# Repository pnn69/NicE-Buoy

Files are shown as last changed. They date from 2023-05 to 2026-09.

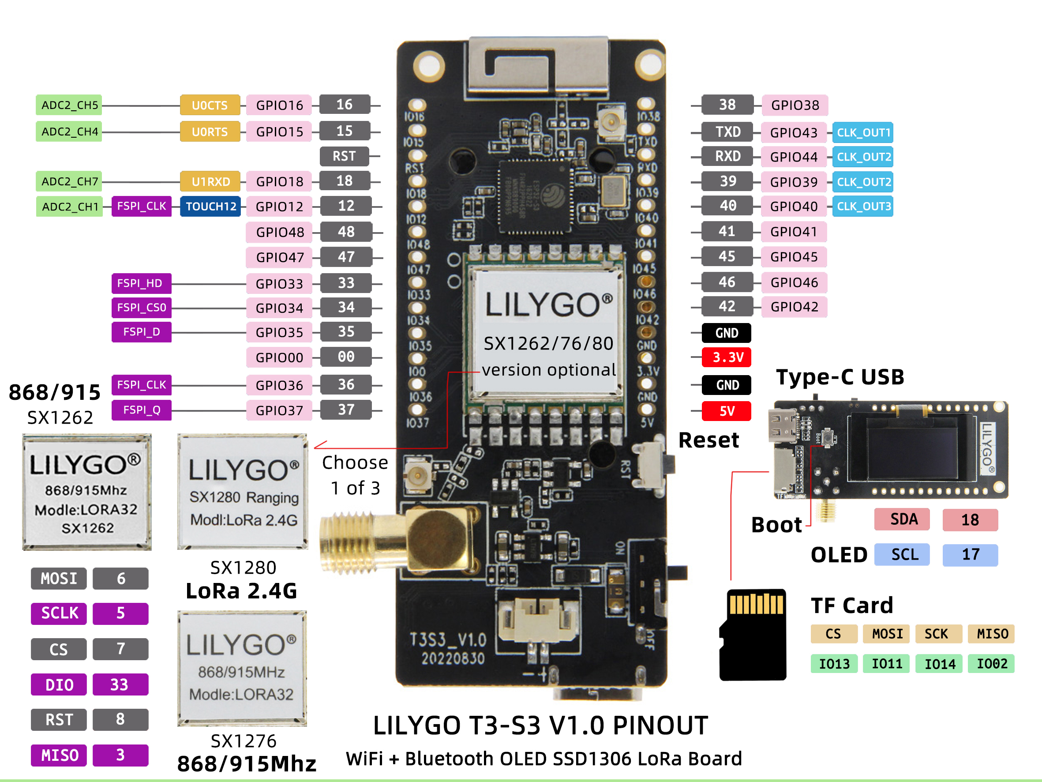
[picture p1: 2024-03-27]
Doc/LilygoEsp32LoraPinout.jpeg

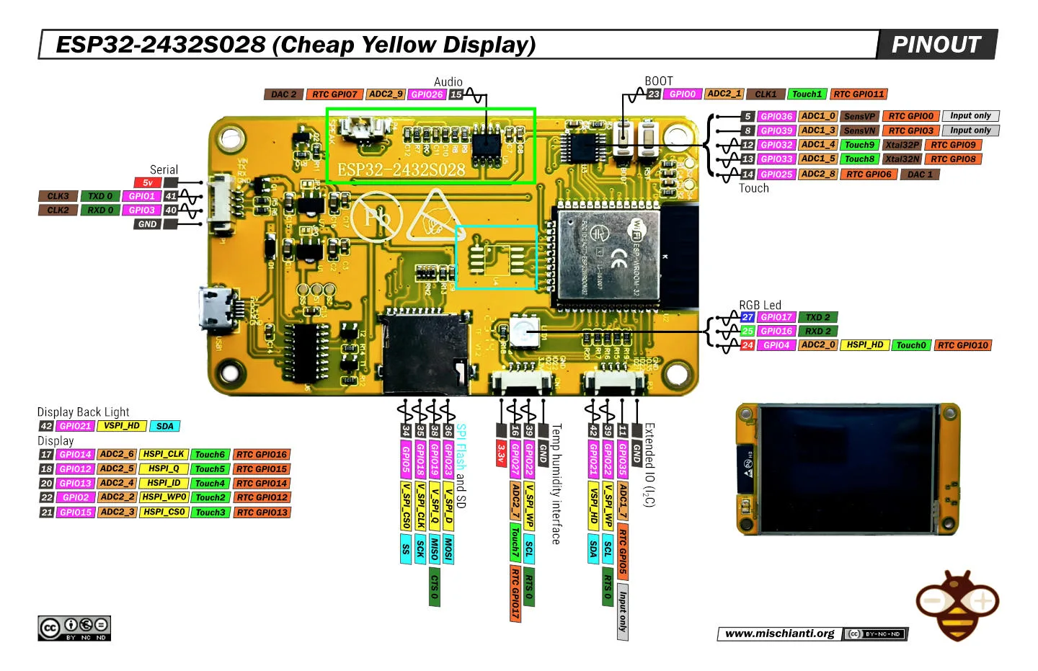
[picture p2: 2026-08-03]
Firmware/RoboCYD/Doc/ESP32-2432S028-ili9341-touch-Cheap-Yellow-Display-pinout-low.jpg.webp

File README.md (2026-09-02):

# NicE-Buoy Autonomous Marine System Firmware

Welcome to the master repository for the **NicE-Buoy Autonomous Marine System**. This codebase powers a highly reliable, dual-processor autonomous marine buoy designed for GPS lock-to-position, remote configuration, automated sailing, and live telemetry tracking over LoRa and WiFi (UDP).

---

## 📌 Project Overview

NicE-Buoy is an industrial-grade marine robotic system consisting of multiple hardware and software components. Each buoy uses a **dual-ESP32 architecture** split into a **Top Unit (RoboTop)** and a **Sub Unit (RoboSub)**, connected by a single-wire half-duplex serial link. This physical decoupling isolates high-frequency navigation, radio communication, and web server tasks (Top) from raw thruster driving, compass polling, and the PID motor loops (Sub).

Alongside the buoys sit two shore-side controllers: **RoboCYD**, a touchscreen unit that doubles as the field WiFi access point, and **RoboLora**, a USB/WiFi LoRa gateway.

---

## 🏗️ System Architecture

```
        ┌───────────────────────────┐        ┌───────────────────────────────┐
        │  RoboPythonDisplay (PC)   │        │  RoboCYD (touchscreen)        │
        │  Tkinter dashboard        │        │  - IS the field AP Robo_WiFi  │
        └────────────┬──────────────┘        │  - LoRa RX task + web UI      │
                     │ UDP / LoRa            └───────────────┬───────────────┘
                     │                                       │
        ┌────────────▼──────────────┐                        │
        │  RoboLora (gateway)       │   UDP 1001 (protocol)  │
        │  USB + WiFi <-> LoRa      │   UDP 1002 (debug log) │
        └────────────┬──────────────┘                        │
                     └───────────────┬───────────────────────┘
                                     │  LoRa 868 MHz  +  WiFi/UDP
┌────────────────────────────────────▼────────────────────────────────────────┐
│                                  RoboTop                                    │
│  - GPS polling (TinyGPS++, 0,0 placeholder rejected)                        │
│  - LoraTask: RF telemetry, ACK retry table (10 slots)                       │
│  - WiFiTask: web dashboard, UDP broadcast, OTA, captive portal, mDNS        │
│  - SercomTask: bridge to the Sub          - Button, buzzer, RGB LEDs        │
└────────────────────────────────────┬────────────────────────────────────────┘
                                     │  single-wire half-duplex UART
                                     │  Top TX 22 / RX 21  <->  Sub RX 5 / TX 18
┌────────────────────────────────────▼────────────────────────────────────────┐
│                                  RoboSub                                    │
│  - Dual ESC thrusters (BB & SB)     - ICM-20948 9-DoF compass + fusion      │
│  - Rudder & speed PID loops         - Owns ALL tuning in NVS                │
│  - Its own web dashboard (24 endpoints) and OTA                            │
└─────────────────────────────────────────────────────────────────────────────┘
```

The codebase is structured into the following decoupled sub-projects:

1.  **`RoboTop` (Top Unit)** — ESP32, FreeRTOS. Acquires GPS, hosts the HTML5 control dashboard, broadcasts telemetry over UDP and LoRa, and delegates motor execution to the Sub.
    Tasks: `GpsTask`, `LoraTask`, `WiFiTask`, `SerialTask` (SercomTask), `buttonTask`, `LedTask`, `buzzTask`.
2.  **`RoboSub` (Sub Unit)** — ESP32, FreeRTOS. Drives the thrusters, reads the compass, runs the PID loops, and is the **authoritative owner of all tuning parameters** (see below).
    Tasks: `CompassTask`, `EscTask`, `SerialTask`, `WiFiTask`, `LedTask`, `buzzTask`. The rudder and speed PIDs live in `pidrudspeed.cpp`.
3.  **`RoboCYD` (Touchscreen Controller)** — ESP32 + 320x240 TFT with resistive touch. Displays the fleet, sends commands, and **raises the field access point `Robo_WiFi`** when no home network is present. Has a dedicated LoRa receive task and serves both a dashboard and a standalone fullscreen map.
4.  **`RoboDependency` (`RoboCompute` + `RoboTone` libraries)** — shared code linked by Top and Sub. Navigation maths (`RouteToPoint`), the unified `RoboStruct`, `formatFloat`, and the telemetry encoder/decoder (`rfCode` / `rfDeCode`).
5.  **`RoboLora` (LoRa Gateway)** — USB-and-WiFi to LoRa gateway with its own web UI. Relays operator commands to the buoys; stamps its outgoing frames with sender ID `0x99`.
6.  **`RoboPythonDisplay` (Python GUI Monitor)** — Tkinter desktop dashboard (`RoboControl.py`) for up to 3 buoys: windroses, thruster indicators, battery voltages, PID menus.
7.  **`RoboChargingStation`** — solar monitoring and charging dock firmware.

### Who owns what

Worth stating plainly, because it drives a lot of the design:

*   **The Sub owns the tuning.** PID gains, compass offset, `holdRad`, thruster inversion and swap all live in the Sub's NVS. The Top holds a RAM copy only, fetched via `SETUPDATA` when the serial link comes up, and shown on the dashboards until the Sub reports again.
*   **`compassOffset`, `revBB`, `revSB` and `swap_BB_SB` are hull-specific** — they describe the physical boat, not the electronics. Move a Sub to another hull and these travel with it and will be wrong until re-entered.
*   **The Sub has no LoRa.** Its only path to the outside world is the serial line to its Top.

---

## 🌐 Network Layout

Every node follows the same priority list:

```
NicE_WiFi  ->  Robo_WiFi  ->  its own AP
```

*   **At home** everything joins `NicE_WiFi`.
*   **In the field**, when no `NicE_WiFi` is in reach, the **CYD becomes `Robo_WiFi`** (password `geenanker`, `192.168.1.1/24`, 8 client slots) and the Tops and RoboLora join it.
*   **A node that finds neither** raises its own AP — `TOP_<id>`, `SUB_<id>`, `LORA_<id>`, password `geenanker`, on `192.168.4.1` — and keeps hunting underneath it. Joining that AP opens the dashboard automatically via a captive portal.
*   **The Sub deliberately skips `Robo_WiFi`**, to keep the CYD's client slots for the Tops and a phone. It costs nothing: the Sub never transmits on UDP anyway, and all of its telemetry reaches you folded into the Top's `TOPDATA`.

**mDNS** gives every node a stable name that works in both modes — `top-<id>.local`, `sub-<id>.local`, `robocyd.local`, `lora-<id>.local`. ArduinoOTA registers the responder; nothing else may call `MDNS.begin()`, as a second responder has crashed this hardware before.

**UDP ports:** `1001` carries the protocol; `1002` carries a plain-text debug log (see the RoboTop README).

---

## 📡 Communication Protocol & Frame Format

The system communicates using a lightweight, proprietary, ASCII-based comma-separated protocol designed to optimize RF bandwidth while remaining human-readable.

### Frame Anatomy
```
$TargetID,SenderID,AckType,CommandType,Status,Param1,Param2,...,ParamN*CRC\n
```

*   **`$`**: Starting sentinel character.
*   **`TargetID`**: Address of the recipient. **All IDs are hexadecimal.** A buoy's ID is the low four bytes of its MAC (e.g. `b7a5b578`). `1` (`BUOYIDALL`) is the broadcast address; `0` is treated as a legacy broadcast.
*   **`SenderID`**: Address of the transmitting station. `99` (i.e. `0x99`) is the web UI / RoboLora and `98` is the CYD display. **These two are the only senders whose broadcasts a buoy will act on** — a broadcast command from a peer buoy is ignored, which is what stops one buoy commanding another.
*   **`AckType`**: Packet type classification:
    *   `1 (GET)`: Request parameter values.
    *   `2 (SET)`: Modify parameter values.
    *   `3 (GETACK)`: Request command execution with receipt verification.
    *   `4 (ACK)`: Receipt confirmation.
    *   `6 (INF)`: Telemetry status update, or an *answer* to a question.
*   **`CommandType`**: Integer mapping to system command (e.g., `51` for `TOPDATA`, `19` for `BUOYPOS`, `83` for `SETUPDATA`, `47` for `DIRDIST`, `21` for `LOCKPOS`, `23` for `DOCKPOS`).
*   **`Status`**: Current state machine status of the buoy (`7 IDLE`, `13 LOCKED`, `16 DOCKED`, …).
*   **`Params`**: Dynamic floating-point or integer parameters depending on the command.
*   **`*`**: End-of-payload delimiter.
*   **`CRC`**: 2-character hexadecimal CRC calculated by XOR'ing all characters between `$` and `*`.

> **Broadcasts that expect an ACK are a trap.** An ACK for `IDr = BUOYIDALL` can never match in `removeAckMsg()`, so a `SET` or `GETACK` broadcast sits in the LoRa retry table for all five retransmits and blocks a slot. Broadcast beacons must use `INF`.

---

## 🚀 Advanced Telemetry Optimizations

### 1. Bandwidth Compression
To maximize LoRa airtime efficiency and range, telemetry strings undergo two compression steps in `RoboCompute.cpp`:
*   **Float Trailing Stripping**: `formatFloat()` trims redundant trailing zeros and decimal points (e.g. `12.5000` becomes `12.5`).
*   **Zero Compression**: `RoboCode()` compresses consecutive zero fields to empty strings (e.g. `,0,0,0,0,` becomes `,,,,,`).

### 2. The Top-to-Sub Link, and Why One-Way Failures Matter
The Top and Sub share **one wire**, half duplex, with hardware separating the two directions (opto-isolated; see `Datasheets/`). The firmware configures two GPIOs per board — Top TX 22 / RX 21, Sub RX 5 / TX 18 — but that is **not** two conductors.

*   **The diagnostic consequence:** if the connector or the wire fails, traffic stops in *both* directions. A failure in **one direction only** therefore cannot be the plug — it is in the direction-separation circuitry, which is per board. Swapping a Sub between hulls localises such a fault to a specific board.
*   `SercomTask` implements **echo filtering**, discarding frames whose sender ID is its own, because a transmitter hears itself on a shared wire.
*   **Implicit ACKs**: any valid `INF` response from the Sub signals that it processed the command, clearing the retry queue without extra traffic.
*   **The Sub sleeps.** After reconnection it sits in power-down and only wakes on an incoming command — send one, wait, then it communicates. Do not read a quiet Sub as a fault until it has been nudged.

### 3. Hardware Self-Healing Watchdogs
*   **LoRa transceiver watchdog**: if transmission fails for 500 ms the SPI/state machine is assumed locked and `InitLora()` forces a full re-init.
*   **Compass watchdog**: static I2C readings under thruster power trigger `COMPASS STUCK - REINIT`.
*   **Serial watchdog**: the Top clears `isSerConnected` after 2 s of silence and re-requests `SETUPDATA` when the Sub returns.
*   **Stack headroom is observable.** The Top's `/data` reports `StkLoop`, `StkLora`, `StkWifi`, `StkSer` and heap figures. A LoRa task running on 100 bytes of stack was the cause of a hard-to-find panic; check these after any change that adds work to a task.

---

## 🧭 In-Field Navigation Calibration State Machines

1.  **In-Field Compass Spin Calibration** — self-guided rotation while measuring magnetic min/max to derive hard-iron offsets.
2.  **In-Field Offset Alignment** — sails a straight leg on compass heading, compares the GPS track, and writes the difference to the stored compass offset.
3.  **Guided 8-Point Compass Calibration** — the hull is turned to the compass's own zero and then indexed round a mechanical fixture 45° at a time, one capture per mark. Produces the 8-point correction table, which is held on the Sub and reported through `SETUPDATA`. The table describes the hull's magnetic deviation only; which way the sensor is bolted in is a separate setting (**Set as North**), applied after the table.

    A GPS-based version of this used to exist, sailing eight 100 m legs and inferring the table from the track. It was removed when the mounting offset moved out of the table's input — its residual arithmetic assumed the old ordering.

---

## 🛠️ Developer Guide

### Prerequisites
*   **Firmware**: [VS Code](https://code.visualstudio.com/) + [PlatformIO IDE](https://platformio.org/).
*   **Python Monitor**: Python 3.10+ with `pyserial` and `tkinter`.

### Compilation & Flash Commands
```bash
pio run                      # build
pio run -t upload            # upload (OTA by default for Top and Sub)
pio device monitor           # serial monitor
```

### Over-The-Air (OTA) Updates
`RoboTop` and `RoboSub` default to `upload_protocol = espota`, so a plain upload goes over the network:

```bash
pio run -t upload --upload-port 192.168.1.71        # by address
pio run -t upload --upload-port top-b7a5099c.local  # or by mDNS name
```

`RoboCYD` and `RoboLora` have **no espota configuration** in their `platformio.ini` (their `upload_port` names a COM port that may not exist), so flash those directly:

```bash
python ~/.platformio/packages/framework-arduinoespressif32/tools/espota.py \
       -i <ip> -p 3232 -f .pio/build/<env>/firmware.bin -r
```

A RoboTop change that touches `data/` also needs `pio run -t uploadfs` — the web page lives in SPIFFS.

> Renaming an SSID or changing the WiFi policy must be rolled out to **the whole fleet at home on `NicE_WiFi`**. A device left on the old scheme cannot be reached in the field.

### Running the Python GUI Dashboard
```bash
pip install pyserial
python RoboPythonDisplay/RoboControl.py
```

---

## 📜 License & Contributions
This project is proprietary and confidential. For contributions, pull requests, or feature requests, contact **Peter de Nijs** (`pnn69pnn@gmail.com`).

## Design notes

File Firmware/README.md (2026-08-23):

# NicE-Buoy Firmware

This directory holds every firmware image in the system. For the system-level picture — architecture, the frame format, the protocol rules and the calibration state machines — see the [repository README](../README.md). This file is the firmware index: what each project is, how they are built and flashed, and the conventions they share.

> These two files used to be near-identical copies, which is how they drifted apart. Keep system-wide material in the root README and firmware-specific material here.

---

## Projects

| Directory | Target | Role | README |
|---|---|---|---|
| `RoboTop` | ESP32 (`esp32dev`) | Buoy top: GPS, LoRa, WiFi, web dashboard, commands the Sub | [link](RoboTop/README.md) |
| `RoboSub` | ESP32 (`esp32dev`) | Buoy sub: thrusters, ICM-20948 compass, PID, owns all tuning | [link](RoboSub/README.md) |
| `RoboCYD` | ESP32 + 320x240 TFT | Touchscreen controller; **is** the field AP `Robo_WiFi` | [link](RoboCYD/README.md) |
| `RoboLora` | ESP32 (`pico32`) | USB/WiFi to LoRa gateway with web UI | [link](RoboLora/README.md) |
| `RoboDependency` | library | `RoboCompute` (maths, `RoboStruct`, codec) and `RoboTone` | [link](RoboDependency/README.md) |
| `RoboChargingStation` | ESP32 | Solar monitoring and charging dock | [link](RoboChargingStation/README.md) |
| `RoboPythonDisplay` | Python | Tkinter desktop dashboard | [link](RoboPythonDisplay/README.md) |

`RoboTop` and `RoboSub` both link `RoboDependency`; change `RoboCompute` and **both** must be rebuilt and reflashed.

---

## 📶 WiFi policy (all devices)

One priority list, identical everywhere:

```
NicE_WiFi  ->  Robo_WiFi  ->  own AP
```

| Device | Priority list | In the field |
|---|---|---|
| RoboCYD | `NicE_WiFi` → *becomes* `Robo_WiFi` | the field AP |
| RoboTop | `NicE_WiFi` → `Robo_WiFi` → `TOP_<id>` | joins the CYD |
| RoboSub | `NicE_WiFi` → `SUB_<id>` | always its own AP |
| RoboLora | `NicE_WiFi` → `Robo_WiFi` → `LORA_<id>` | joins the CYD |

*   `NicE_WiFi` password `!Ni1001100110`; `Robo_WiFi` and every fallback AP use **`geenanker`**.
*   `Robo_WiFi` is `192.168.1.1/24` with **8 client slots** (the Arduino default of 4 is exactly three Tops plus a phone). Per-node fallback APs are `192.168.4.1`, each its own gateway.
*   **The Sub skips `Robo_WiFi` on purpose**, to keep the CYD's slots for the Tops and a phone. Nothing is lost — the Sub never transmits on UDP; its telemetry reaches you inside the Top's `TOPDATA`.
*   Nodes **never stop hunting**: the fallback AP runs in `WIFI_AP_STA`, so a buoy on its own AP keeps looking for a real network underneath it. It will not tear its AP down while a client is connected.
*   No scanning. `WiFi.scanNetworks()` blocks for seconds and drags the single radio off the AP channel; the SSIDs are tried in order with a blind `WiFi.begin()` instead.

**Getting in without an IP address** — two mechanisms, because neither covers both modes:

*   **Captive portal** while the node is an AP: wildcard DNS on port 53 means the phone's own connectivity probe lands on the dashboard. Off when the node is a station, where a 404 must stay a 404.
*   **mDNS** in both modes: `top-<id>.local`, `sub-<id>.local`, `robocyd.local`, `lora-<id>.local`.

> Only `ArduinoOTA.begin()` may initialise mDNS. A second `MDNS.begin()` — or an `MDNS.end()` while OTA holds the responder — has crashed this hardware before. Add records with `MDNS.addService()` on top of the responder OTA created.

> Changing an SSID or the policy must be rolled out to the **whole fleet at home on `NicE_WiFi`**. A device left on the old scheme is unreachable in the field.

---

## 🔌 UDP ports

| Port | Traffic |
|---|---|
| `1001` | protocol frames (`$...*CRC`) — telemetry and commands |
| `1002` | plain-text debug log from Tops and Subs, silent at idle |

Listening to the debug channel is the quickest way to see what a buoy is doing:

```bash
python -c "import socket; s=socket.socket(2,2); s.bind(('',1002));
while 1: print(s.recvfrom(2048)[0].decode('utf-8','replace'), end='')"
```

---

## 🛠️ Build and flash

```bash
pio run                      # build
pio run -t upload            # upload
pio device monitor           # serial monitor
```

| Project | Default upload | Notes |
|---|---|---|
| `RoboTop` | OTA (`espota`, `192.168.1.71`) | a `data/` change also needs `pio run -t uploadfs` |
| `RoboSub` | OTA (`espota`, `192.168.1.189`) | sealed hull, never on USB in practice |
| `RoboCYD` | serial (`COM15`) | **no espota config** — see below |
| `RoboLora` | serial (`COM30`) | **no espota config** — see below |

Override the target per invocation:

```bash
pio run -t upload --upload-port 192.168.1.78
pio run -t upload --upload-port top-b7a5b578.local
```

`RoboCYD` and `RoboLora` name COM ports that may not exist on the machine you are using, but both run ArduinoOTA, so flash them directly:

```bash
python ~/.platformio/packages/framework-arduinoespressif32/tools/espota.py \
       -i <ip> -p 3232 -f .pio/build/<env>/firmware.bin -r
```

Environments: `RoboTop` → `robo-esp`, `RoboSub` → `robo-esp-v3`, `RoboCYD` → `cyd`, `RoboLora` → `pico32`.

---

## Conventions worth knowing before editing

*   **The Sub owns the tuning.** PID gains, `compassOffset`, `holdRad`, `revBB`/`revSB`/`swap_BB_SB` live in the Sub's NVS. The Top keeps a RAM copy fetched via `SETUPDATA`. `compassOffset` and the thruster flags are **hull-specific** and do not belong to the board they are stored on.
*   **The Sub has no LoRa.** Its only link to the outside is the serial line to its Top.
*   **A broadcast must never ask for an ACK.** `IDr = BUOYIDALL` with `ack = SET`/`GETACK` can never be matched in `removeAckMsg()` and jams a LoRa retry slot for five retransmits. Use `INF` for beacons.
*   **Only `0x99` (web/RoboLora) and `0x98` (CYD) may command by broadcast.** A buoy ignores broadcast commands from a peer buoy — that is what stops one buoy driving another.
*   **Watch task stack headroom.** The Top's `/data` exposes `StkLoop`, `StkLora`, `StkWifi`, `StkSer`, `HeapFree`, `HeapMin`, `HeapMaxBlk`. A LoRa task left with 100 bytes of stack caused a panic that looked like everything except what it was.

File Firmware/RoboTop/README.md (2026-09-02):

# RoboTop — Autonomous Marine Buoy Master Supervisor Firmware

The **`RoboTop`** firmware runs on the master ESP32 microcontroller of the NicE-Buoy Autonomous Marine System. It serves as the primary intelligence, networking, and supervisory node, managing global positioning, wireless telemetry channels, client-facing control dashboards, and delegating physical motor actions to the Sub Unit (`RoboSub`).

---

## 🏗️ Architecture & Core Tasks

RoboTop leverages FreeRTOS to coordinate real-time operations across the ESP32's dual cores:

```
┌─────────────────────────────────────┬─────────────────────────────────────┐
│               Core 0                │               Core 1                │
├─────────────────────────────────────┼─────────────────────────────────────┤
│ WiFiTask   8192  web, UDP, OTA      │ LoraTask   8192  SPI long-range RF  │
│ SerialTask 6000  link to the Sub    │ GpsTask    2000  TinyGPS++ polling  │
│                                     │ buttonTask 2048  press detection    │
│                                     │ LedTask    2000  / buzzTask 2048    │
└─────────────────────────────────────┴─────────────────────────────────────┘
                 loop() on core 1: navigation, state machine, RF dispatch
```

The numbers are stack sizes in bytes, and they matter. `LoraTask` was once given 4000 and ran with **100 bytes of headroom**, which tripped the stack canary under load and produced a panic that pointed at every task except the guilty one. Live headroom is published in `/data` as `StkLoop`, `StkLora`, `StkWifi`, `StkSer` — check it after any change that adds work to a task.

---

## ⚡ Core Functional Modules

### 1. GPS Acquisition & Navigation Telemetry
*   **Hardware Interface**: GPS module over UART, polling raw NMEA sentences.
*   **Sentence Parsing**: `TinyGPSPlus` extracts latitude, longitude, heading and speed over ground.
*   **Fix validity**: a fix requires `isValid()` **and** an age under 2000 ms **and** a position that is not `0,0`. `isValid()` alone only means "a position field was parsed" — it stays true across a sentence carrying zeros, and passing that on sends the rest of the firmware chasing a point off the coast of Africa.

### 2. Long-Range LoRa Telemetry (`loratop.cpp`)
*   **Hardware Interface**: SPI LoRa transceiver for bidirectional telemetry with the shore station and the other buoys. **433 MHz** (`LoRa_frequency` in `loratop.h`), library defaults otherwise — SF7, 125 kHz, CR 4/5, hardware CRC on. The band is `#define`d separately here, in RoboLora and in RoboCYD, and all three must match; see the RoboLora README.
*   **Retry & ACK Protocol**: `pendingMsg[10]` holds frames sent with `ack = GETACK` or `SET`, retransmitting each up to 5 times until acknowledged.
    > **A broadcast must never ask for an ACK.** An ACK for `IDr = BUOYIDALL` can never match in `removeAckMsg()`, so the frame occupies its slot for all five retransmits and re-broadcasts each time. Beacons use `INF`.
*   **Self-Healing SPI Watchdog**: if transmission fails over a 500 ms window the radio is assumed locked and `InitLora()` forces a full re-init.

### 2b. The transparent repeater

A node relays frames addressed to **someone else**, in case that someone is out of the sender's
range but inside ours. Every rule below exists because the naive version of it failed in the field,
so they are worth reading before changing any of them. Same design in `RoboLora`.

**Unicast only — with one exception.** Broadcasts are not relayed. They used to be, simply because
a broadcast is not "addressed specifically to us" and so fell through into the relay branch. All
periodic telemetry is broadcast (`handleTimerRoutines` sets `IDr = BUOYIDALL`), so every Top
rebroadcast every other Top's telemetry. At SF7/125 kHz a 116-byte `TOPDATA` is ~195 ms of airtime,
so three locked buoys sending one frame a second came to roughly **195% channel occupancy**. The
channel could not carry it, and what got dropped was the traffic that mattered — a COMPUTE STARTLINE
would compute and its `SETLOCKPOS` frames would never arrive. Relaying a broadcast buys nothing
anyway: a node close enough to hear the relay had almost certainly heard the original, and every
buoy broadcasts its own telemetry regardless.

The exception is **`LORA_LINK`**, and it is an exception precisely because neither of those
arguments holds: the whole point of a link report is to arrive from a node you *cannot* hear
directly, and nobody else can produce it on that node's behalf. One frame a minute per node is about
0.2% of the channel.

**Dedup cache** (`checkAndRecordRepeaterMessage`, 16 entries, 20 s). A frame is matched verbatim and
relayed at most once per 20 s window. This is what stops a relay going round in circles between two
nodes that can both hear each other.

**Deferred, staggered relays.** A relay is queued with a due time, not transmitted from inside
`onReceive()`. Synchronous relaying meant every node that heard the frame relayed it in the same
millisecond, so the relays collided with each other — and a node is deaf while it transmits, so each
one also missed whatever else was on the air. Nothing about that design could work with more than
one relay in the field.

The delay comes from the node's **own MAC** (`repeatDelayMs()`), folded down to one of
`REPEAT_NODE_SLOTS`, so two nodes holding the same frame are never due at the same moment. Pure
randomness would still collide occasionally; a MAC-derived slot cannot, provided the two boards fold
to different slots. A small random jitter is added only to break the tie when they do not.

| Constant | Value | Why |
|---|---|---|
| `REPEAT_SLOTS` | 4 | relays that may be waiting at once |
| `REPEAT_NODE_SLOTS` | 5 | distinct per-MAC time slots |
| `REPEAT_SLOT_MS` | 250 | wider than the airtime of any frame relayed, so slot 0 finishes before slot 1 starts |
| `REPEAT_BASE_MS` | 40 | dead time before slot 0, lets the sender's tail clear |
| `REPEAT_JITTER_MS` | 60 | tie-break when two MACs fold to the same slot |
| `REPEAT_EXPIRY_MS` | 3000 | give up on a relay the radio will not accept |

**The slot budget is bounded by the retry interval, not chosen freely**: `4 x 250 + 40 + 60 =
1100 ms`, comfortably inside the ~1500 ms the sender's retry table waits. Widen the slots or add
more and relays start landing after the retransmit they were meant to save.

**Cancel on heard** (`cancelRepeat`). Before anything else in `onReceive()`, a queued relay matching
the frame just heard is dropped — somebody beat us to it, or the sender resent it. Deliberately
ahead of the early returns, so it applies to frames addressed to us as well. Combined with the
stagger, this means **in practice only the lowest-slot node in range actually transmits**: the
others hear that relay, drop their copy, and the frame reaches the far node exactly once.
`cancelRepeatOnAck` does the same when an ACK proves the target already has it — matched on
`cmd` + `target_id` rather than on the text, because the ACK is not the frame.

**Two boards can share a slot**, and with three Tops and five slots that is not unlikely. Not fatal:
both relay at once, that relay is lost to the collision, and the sender's next retransmit produces a
fresh attempt with newly drawn jitter. The stagger removes the *guaranteed* collision the old
synchronous design had; it does not have to remove every possible one.

**A wedged radio does not disable the repeater.** If `sendLora()`'s inter-packet guard keeps
refusing, the slot stays busy and is retried next pass rather than being dropped — the old
fire-and-forget call lost the relay on every guarded return. After `REPEAT_EXPIRY_MS` the relay is
stale enough to be useless and the slot is freed, which is also what stops one stuck transceiver
silently holding every slot.

### 2c. The button

**Every action ends in a long press.** Nothing is bound to a short-press-only sequence, and that is
the design rather than an accident of it. This button is on a buoy that gets knocked, carried and
stowed, and the previous map had *lock/unlock on a single short press* and *sail to the dock on
five*. Both were one accidental knock away from a boat leaving on its own. A long press cannot be
produced by a bump, so the short presses became a selector and the long press became the trigger.

`countKeyPressesWithTimeoutAndFinalLongPress()` returns `100 + (presses in the sequence)`, and the
closing long press is one of them — so "three short then long" arrives as `104`.

| Sequence | Code | Action | On success | On failure |
|---|---|---|---|---|
| long | `101` | lock / unlock | rising arpeggio (lock) or descending (unlock) | error tone — no GPS fix |
| short, long | `102` | align start line (`COMPUTESTART`) | rising | error tone |
| short ×2, long | `103` | align track (`COMPUTETRACK`) | rising | error tone |
| short ×3, long | `104` | extend the start line by `START_LINE_STEP_M` (`EXTENDSTART`) | rising | error tone |
| short ×4, long | `105` | sail to the dock position (`DOCKING`) | rising | — |
| short ×9, long | `110` | store here as the dock position (`STOREASDOC`) | rising | error tone |

Anything else beeps the error tone and does nothing — deliberately including every plain short
press. Silence would be indistinguishable from a flat battery or a jammed switch.

> **`110` stores wherever the buoy IS.** Nine short presses and a long one is an easy sequence to
> arrive at by accident, it overwrites the stored dock with the buoy's current position, and nothing
> keeps the previous value. That happened on the bench, 3.8 km from the water, and there was no way
> to put it back - so `SETDOCKPOS` (22) now writes the dock from coordinates over the air. The
> command number and the codec always existed; only the Top's handler was missing. `DOCKPOS` (23)
> with `ack = GET` reads it back out of NVS, which is how a write should be checked.

> **Two codes have MOVED.** `105` used to be store-as-dock and is now *dock*; `110` used to be the
> desk magnetic calibration and is now *store-as-dock*. Muscle memory from the old scheme will do
> the wrong thing.

**Extend is not a re-align.** `EXTENDSTART` keeps the line's midpoint *and its bearing* and only
moves the ends apart, half the step each. It is the answer to "same line, a bit longer", which is
not what `COMPUTESTART` does — that squares the line to the wind, and a race officer asking for ten
more metres is not asking to have the line rotated as well. Consequently it needs **no wind reading
at all**, so unlike the two align actions it still works on a buoy whose compass has failed. It
takes the same two-locked-buoys guard, because an unlocked buoy carries a stale target and the line
would be extended through wherever it last was. Roles are left untouched: pushing a buoy further out
along the bearing it is already on cannot change which side of the line it is.

The step is fixed at 10 m (`START_LINE_STEP_M`) rather than settable. This is the button on the
buoy: it has no way to show a number and no way to take one back. Press it twice for twenty metres.

#### Two beeps that were missing

*   **Storing the dock position** played `beep(1000)` — a single flat 1000 Hz tone, which is
    *exactly* the tone the button plays on every physical press. "The dock position is stored" was
    indistinguishable from "I felt you press the button". It plays the rising arpeggio now, like
    every other successful action.
*   **Locking without a GPS fix** was completely silent — the long press did nothing and said
    nothing, which reads the same as a flat battery, a jammed switch or a missed press. It is also
    the moment the operator most needs telling, because the boat is already in the water. It beeps
    the error tone now.

Everything else already gave the right feedback: `LOCKING` the rising arpeggio, `IDLING` the
descending unlock pattern, and every compute a rising tone on success and the error tone on refusal.

### 3. WiFi, Web Dashboard and OTA (`topwifi.cpp`)
*   **Priority list**: `NicE_WiFi` → `Robo_WiFi` → its own `TOP_<id>` AP. No scanning — the SSIDs are tried in order with a blind `WiFi.begin()`, because `WiFi.scanNetworks()` blocks for seconds and drags the single radio off the AP channel.
*   **Passwords**: `NicE_WiFi` is `!Ni1001100110`; `Robo_WiFi` and the fallback AP are **`geenanker`**.
*   **The fallback AP keeps hunting.** It runs in `WIFI_AP_STA` on `192.168.4.1` (its own gateway, 8 client slots) and continues looking for a real network underneath — but it will **not** tear itself down while a client is connected.
*   **Captive portal** while in AP mode: wildcard DNS on port 53, so joining `TOP_<id>` opens the dashboard by itself. Disabled as a station, where a 404 must remain a 404.
*   **mDNS**: reachable as `top-<id>.local` in both modes. Only `ArduinoOTA.begin()` may initialise the responder — a second `MDNS.begin()` has crashed this hardware.
*   **HTML5 Dashboard**: served from SPIFFS and streamed straight from the file, not cached in a RAM `String` (a fragmented heap silently truncated the page mid-`<script>`). The page **polls `/data`**; there is no WebSocket on the Top.
*   **Endpoints**: `/` (dashboard), `/data` (JSON telemetry), `/command` (actions).
*   **Dual-rate transmit scheduler**: UDP telemetry every **250 ms** for fluid web feedback; LoRa throttled to **5 s** with randomised jitter for collision avoidance, battery and duty-cycle reasons.

### 4. Single-Wire Half-Duplex Serial Bridge (`sercom.cpp`)
*   **Physical layer**: **one shared wire**, half duplex, with hardware separating the directions (opto-isolated). The firmware names two GPIOs per board — Top **TX 22 / RX 21**, Sub **RX 5 / TX 18** — but that is not two conductors.
    > **Diagnostic consequence:** a bad connector or wire stops traffic in *both* directions. A failure in **one direction only** is therefore in the direction-separation circuitry, which is per board — swap the Sub between hulls to localise it.
*   **Echo filtering**: a transmitter hears itself on a shared wire, so frames whose sender ID is our own are discarded.
*   **Implicit ACKs**: any valid `INF` from the Sub clears the retry buffer.
*   **Watchdog**: `isSerConnected` clears after 2 s of silence and a fresh `SETUPDATA` request is issued when the Sub returns.
*   **The Sub sleeps** after reconnection and only wakes on an incoming command — send one, wait, then it talks.

### 5. Who owns the tuning
The **Sub** owns it. PID gains, `compassOffset`, `holdRad`, `revBB`/`revSB`/`swap_BB_SB` live in the Sub's NVS; the Top keeps a RAM copy fetched with `SETUPDATA` when the serial link comes up. `/data` reports `rev` (the count of replies received) and `SubOk` (serial alive) — `rev: 0` with real values elsewhere means the Top has never heard back and is running on zeroed gains.

**The mirror is re-read every `SUB_SETUP_RESYNC_MS` (20 s), not only on connect.** Anything that
changes a setting without going through a Setup dialog — `SET_AS_NORTH`, the Sub's own web page,
an in-field calibration — used to leave this Top serving a stale value indefinitely; measured on the
bench, a Sub on `-43.30` against a Top still reporting `-53.00` minutes later. Re-asking the owner
is the only thing that covers all of them, and it is self-healing.

> **Consequence for anything that reads `/data` or the broadcast live.** The reply goes out to
> `BUOYIDALL` on **both** transports, asked for or not. That is safe for the web Setup dialog, which
> fills its fields once on open, and it was written with that in mind. It is *not* safe for a client
> that edits a live-updating copy of the same struct: the CYD's Setup screen did exactly that, and
> every value dialled in was replaced by the buoy's own a few seconds later. The fix belongs at the
> reading end — see the RoboCYD README — but the behaviour to design against is here.

### 6. Automated Regatta Start Line & Track Calculations
To facilitate competitive sailing regattas, RoboTop coordinates the positions of multiple buoys to automatically establish a fair, geometrically synchronized starting line:

*   **Intelligent Triangulation & Role Determination (`calcTrackPos`)**: Rather than relying on static or arrival-order database slots, RoboTop uses geometric triangulation and wind vectors to determine the roles of the three buoys (`PORT`, `STARBOARD`, `HEAD`):
    *   **Starting Line Identification**: Computes the Great-Circle distances between all three buoy pairs. The two buoys with the **shortest distance** between them are the starting line pins; the furthest is the upwind **HEAD** buoy.
    *   **Port vs. Starboard Allocation**: Calculates the bearing between the two pins and measures the signed smallest angular difference against $W_{\text{dir}}$. Positive ($\ge 0^\circ$) makes the first buoy **PORT**; negative makes it **STARBOARD**.
*   **$W_{\text{dir}}$ is the mean of BOTH pins' wind, not one buoy's (`meanWindDir`)**: it used to
    be `rsl[0].wDir` — whichever buoy the command happened to reach. Two anemometers a line's length
    apart disagree by a few degrees in steady air and by rather more in a shifty one, and there is
    no reason to prefer either; the mean squares the line to the wind *across* the line, which is
    the wind the fleet actually starts in. In a three-buoy course the upwind **HEAD** mark is left
    out of the average on purpose — it is no part of the line, and it is the furthest from where the
    start happens. All three consumers now use it: `recalcStartLine()`, `reCalcTrack()` (which hangs
    the head mark's bearing, the offset back down to the line and the starboard side off this one
    figure) and `calcTrackPos()`. Slot 0 remains the fallback, because `handleStatus()` puts this
    buoy's filtered wind there and the compute guards have already refused to run without it.
*   **Geographical Midpoint & Width**: Computes the pins' midpoint by coordinate average and the line width $d$ by Haversine.
*   **Wind-Aligned Perpendicular Squaring (`recalcStartLine`)**: The line must be exactly perpendicular to the wind:
    *   Port end bearing: $\theta_{\text{Port}} = (W_{\text{dir}} + 270^\circ) \bmod 360^\circ$
    *   Starboard end bearing: $\theta_{\text{Starboard}} = (W_{\text{dir}} + 90^\circ) \bmod 360^\circ$
*   **Vector Position Projection (`adjustPositionDirDist`)**: Projects new targets outward from the midpoint along those bearings by $d/2$, squaring the line to the wind while keeping midpoint and length intact. *Length intact* now holds exactly: this function placed with an earth radius of 6371000 m while `distanceBetween()` measured with 6372795 m, so measuring $d$ and then placing at $d$ returned $1.000282\,d$ and every press of ALIGN STARTLINE grew the line by 0.028%. Both use `EARTH_MEAN_RADIUS`. It was 9 mm on a 31 m line and never the reason a line looked a different length — but the whole design of `recalcStartLine()` is that measuring and placing are inverses, and they were not.
*   **The line is computed from the lock TARGETS, not the hulls.** The screens draw it between the
    actual positions, because that is what the crew can see; the arithmetic deliberately does not.
    Feed it hull positions and each press picks up wherever the buoys were wandering inside their
    hold radius, so the line changes length every time it is aligned. Targets are fixed, so the
    length is preserved. You see the hulls, the maths uses the targets.
*   **Asynchronous Coordination Broadcast (`SENDTRACK`)**: Dispatches updated coordinates to Port, Starboard and Head over LoRa.

### 7. Advanced Circular Wind Telemetry & Standard Deviation
*   **Circular Vector Addition (`averageWindVector`)**: Arithmetic averaging fails at the $360^\circ$ wrap (the mean of $350^\circ$ and $10^\circ$ is $180^\circ$ arithmetically but $0^\circ$ physically). Each sample $A_i$ is decomposed into unit vectors:
    $$x_i = \cos(A_i \times \tfrac{\pi}{180}), \quad y_i = \sin(A_i \times \tfrac{\pi}{180})$$
    and recombined with the four-quadrant arctangent:
    $$W_{\text{dir}} = \text{atan2}(\bar{y}, \bar{x}) \times \tfrac{180}{\pi}$$
*   **Yamartino Circular Standard Deviation (`deviationWindRose`)**: from the mean resultant length $R$
    $$R = \frac{\sqrt{(\sum \cos A_i)^2 + (\sum \sin A_i)^2}}{N}, \qquad W_{\text{std}} = \sqrt{-2 \ln R} \times \tfrac{180}{\pi}$$
    $R = 1$ is perfect alignment, $R = 0$ complete dispersal.

### 8. Command Routing Rules (`handleRfData`)
*   `IDr` is matched against our MAC; `1` (`BUOYIDALL`) and `0` are broadcasts.
*   A **broadcast command is only obeyed when the sender is `0x99` (web/RoboLora) or `0x98` (CYD)**. A broadcast from a peer buoy is ignored — this is what stops one buoy commanding another.
*   Frames that are not for us are **bridged to the other interface** (UDP↔LoRa), never back out the one they arrived on, which would loop.
*   `DOCKPOS` is a *question*. The answer is addressed to the asker and sent as `INF`, and an `INF` frame is never answered — otherwise two Tops answer each other's answers indefinitely.

---

## 🩺 Diagnostics

*   **Debug channel** — plain text broadcast on **UDP 1002**, silent at idle. Carries every non-telemetry RF and serial frame, the DOCK/DOCKPOS step markers and every beep with the line that requested it.
*   **Breadcrumbs surviving a panic** — held in `RTC_NOINIT` memory and reported next boot as `Crumb`, `CrumbLora`, `CrumbWifi`, `CrumbSer`. `90–96` = loop phase, `1000+cmd` = RF command dispatched, `2000+cmd` = serial command, `200–206`/`300–303`/`400–403` = LoRa/Sercom/WiFi task.
    > A **power cycle wipes RTC RAM** and the evidence with it. A reset-pin press or a panic reboot preserves it.
*   **`/data` health fields** — `Uptime`, `ResetReason`, `SubOk`, `rev`, the four `Stk*` figures and `HeapFree` / `HeapMin` / `HeapMaxBlk`.

---

## 🛠️ Building & Flashing

PlatformIO environment **`robo-esp`** (`board = esp32dev`). Dependencies: `RoboCompute`, `RoboTone`, Arduino-PID-Library, TinyGPSPlus, FastLED, arduino-LoRa, ArduinoOTA.

```bash
pio run                                              # build
pio run -t upload                                    # OTA, default 192.168.1.71
pio run -t upload --upload-port top-b7a5b578.local   # a different unit
pio run -t uploadfs                                  # required after any data/ change
```

`upload_protocol = espota`, so a plain upload goes over the network — the Tops are not normally on USB.

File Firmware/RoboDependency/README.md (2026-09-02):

# RoboDependency — Shared Static Libraries & Algorithmic Engines

The **`RoboDependency`** workspace houses core statically-linked C++ library engines shared across both the **`RoboTop`** (Master Supervisor) and **`RoboSub`** (Locomotion Engine) firmwares. Decoupling these common engines ensures mathematical consistency and guarantees zero duplication in message encoding.

---

## 🏗️ Library Structure

```
                             ┌────────────────────────┐
                             │     RoboDependency     │
                             └───────────┬────────────┘
                  ┌──────────────────────┴──────────────────────┐
                  ▼                                             ▼
       ┌────────────────────┐                        ┌────────────────────┐
       │    RoboCompute     │                        │      RoboTone      │
       │ - Navigation math  │                        │ - beep() sounder   │
       │ - RoboStruct       │                        │ - Tone / melody    │
       │ - Codec + CRC      │                        │   tables           │
       │ - Zero-compression │                        │                    │
       └────────────────────┘                        └────────────────────┘
```

---

## ⚡ Module Breakdown

### 1. `RoboCompute` Library
`RoboCompute` forms the computational backbone of the buoy system, implementing localized navigation math and data compression pipelines:

*   **Great-Circle Path Math (`RouteToPoint()`)**:
    *   Calculates shortest path bearing angles (0 to 360 degrees) and distances (in meters) between arbitrary GPS coordinates (latitude/longitude) on the earth's surface.
    *   Supplies the core error vectors utilized by the high-speed rudder and speed PID tasks on the Sub Unit.
*   **Unified State Struct (`RoboStruct`)**:
    *   Establishes the global data structure (`mainData`) representing the absolute physical state of the buoy (GPS status, heading, thruster duty cycles, battery state, target waypoints, and PID tuning variables).
    *   Allows seamless, thread-safe data serialization across task loops via mutex locks.
*   **Bandwidth-Saving Float Trailing Stripping (`formatFloat()`)**:
    *   Trims redundant trailing zeros and decimal points (e.g., `24.0000` is packed to `24`, and `1.230` to `1.23`) before packaging payload variables, significantly reducing string lengths.
*   **Zero-Compression Payload Packing (`rfCode()` / `rfDeCode()`)**:
    *   Scans finalized ASCII CSV payloads for repetitive zeros representing inactive fields (e.g., zero error, zero speeds, empty target parameters) and replaces them with adjacent commas (e.g., `,0,0,0,0,` is packed to `,,,,,`).
    *   This dual optimization reduces the average LoRa payload size by up to **45%**, decreasing airtime, saving battery, and reducing channel congestion.

*   **Frame CRC (`addCRCToString()` / `verifyCRC()`)** — also in `RoboCompute`, not `RoboTone`:
    *   Computes a longitudinal parity byte (XOR) over every character between the sentinel `$` and
        the delimiter `*`, rendered as a 2-character hexadecimal string.
    *   Incoming frames whose computed checksum does not match the trailing CRC are discarded.
*   **Circular wind statistics (`averageWindVector()`, `deviationWindRose()`)** — vector averaging
    and Yamartino circular standard deviation, so a wind direction either side of North averages
    correctly instead of landing on 180°.
*   **`meanWindDir(dirA, stdA, dirB, stdB, fallback)`** — the wind a start line is squared against:
    the mean of what the **two line-end buoys** report. It used to be one buoy's reading, whichever
    the command happened to reach. Same circular maths and the same reason as above; a buoy
    reporting `0/0` has *no* reading rather than a northerly, so it is left out, and two exactly
    opposite readings are a fault rather than a wind and return the fallback. Used by
    `recalcStartLine()`, `reCalcTrack()` and `calcTrackPos()`.
*   **`extendStartLine(rsl, metres)`** — grows the start line by `metres`, half to each end,
    keeping the midpoint **and the bearing**. Deliberately not `recalcStartLine()` with a different
    length: that one squares to the wind, and rotating the line is not part of "make it longer". It
    therefore reads no wind at all. Both bearings are taken before either end is written back — move
    one end first and recompute the second bearing from the new midpoint, and the pair can swap ends
    and motor through each other, which is the failure `starboardGoesToFirst()` exists to prevent.
    `trackPos` is left alone, and `MIN_START_LINE_M` stops a line being shrunk to a point, which
    would leave no bearing to grow it back along. New `EXTENDSTART` command, appended at the END of
    `msg_t` so every existing number is unchanged and an un-reflashed node still decodes what it did
    before.
*   **One earth radius (`EARTH_MEAN_RADIUS`)** — `distanceBetween()` measured with 6372795 m while
    `adjustPositionDirDist()` placed with 6371000 m, so placing a point at distance $d$ and
    measuring back returned $1.000282\,d$. `recalcStartLine()` does exactly that round trip, so
    every re-align grew the start line by 0.028%. The two must agree: the whole design of that
    function is that measuring and placing are inverses.

### 2. `RoboTone` Library
`RoboTone` is the **audible feedback** library — it has nothing to do with checksums.

*   **`void beep(int sound, QueueHandle_t buzzer)`** — queues a tone, a melody or an error pattern
    onto a buzzer task. Callers pass a sound id: `1` is the confirmation arpeggio, `2` the
    unlock/idle pattern, `-1` the error tone, and a large value such as `1000` a single fixed tone.
*   **`6` is "that landed in NVS"** — one 2000 Hz chirp for 80 ms, added for settings saves. Its own
    id rather than a reuse, because each neighbour already means something and a save has to be told
    apart from all of them: `10` is the button-press tick, `1` a computation that produced a result,
    `5` the compass-table tune, `-1` failure. Long enough to hear at arm's length over an outboard,
    short enough not to be a tune.

> **Ids carry meaning — check before reusing one.** `beep(-1)` is *failure*, and it had been wired
> to the success path of `SET_AS_NORTH` and, previously, of a compass save in `subwifi.cpp`. A good
> save that sounds like a failure teaches the operator to ignore the buzzer, which costs more than
> the missing feedback did.
*   Holds the tone and melody tables (`hz`, `duration`, `repeat`, `pause`) used by both firmwares.

> Sound is the buoy's only feedback in the field, so beeps carry real diagnostic weight. Note that
> a Top emits a single beep on boot — a burst of beeps usually means it has restarted several
> times, not that it acknowledged several commands.

---

## 🛠️ Integration
Both `RoboTop` and `RoboSub` reference these libraries inside their PlatformIO build
configurations via `lib_extra_dirs`:

```ini
lib_extra_dirs =
    ../RoboDependency

lib_deps =
    RoboCompute
    RoboTone
```

> ## ⚠️ Change this, rebuild both
>
> `RoboCompute` is statically linked into **both** firmwares. A change here is not live until
> `RoboTop` *and* `RoboSub` have both been rebuilt and reflashed — and because `RoboStruct` and the
> codec are shared, a half-updated fleet can end up decoding frames differently at each end. Never
> leave this library uncommitted while the firmwares that depend on it are committed.

`RoboLora` links `RoboCompute` too, so a codec change means rebuilding **three** firmwares.
`RoboCYD` is the exception: it links neither library and parses frames with its own code, so a
protocol change has to be mirrored there by hand.

**The wind mean is one of those hand-mirrored things.** It exists three times on purpose —
`meanWindDir()` here for the squaring the Top performs, `mean_wind_dir()` in the CYD firmware for
the roles and the wind label on the touchscreen, and `mapMeanWindDir()` in `RoboCYD/data/index.js`
for the web map. They must stay in step: if they drift, the three views disagree about which end of
the line is starboard, and there is nothing on any screen to say which one is lying.\n

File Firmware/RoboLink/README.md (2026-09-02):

# RoboLora — Long-Range RF USB Gateway Firmware

The **`RoboLora`** firmware runs on the shore-based or vessel-tethered LoRa-to-USB gateway controller. It serves as the physical hardware transceiver link connecting the PC monitoring station with the autonomous buoys over miles of open water.

---

## 🏗️ Gateway Architecture & Functionality

RoboLora manages the relay of long-range telemetry frames with low latency, bridging long-range RF signals directly into a physical PC COM interface:

```
┌─────────────────┐             ┌───────────────────┐             ┌─────────────────┐
│     RoboSub     │   LoRa RF   │     RoboLora      │ USB Serial  │RoboPythonDisplay│
│       or        │◀───────────▶│   - LoraTask      │◀───────────▶│    (PC GUI)     │
│     RoboTop     │             │   - SercomTask    │             │                 │
└─────────────────┘             └───────────────────┘             └─────────────────┘
```

---

## ⚡ Core Functional Modules

### 1. LoRa Physical Transceiver Layer (`LiLlora.cpp` / `LiLlora.h`)
*   **Hardware Interface**: Controls an SPI-connected LoRa transceiver (e.g., RFM95/SX1278) to broadcast and receive long-range RF packets.
*   **433 MHz, and nothing else is configured.** `LoRa_frequency` is `433E6` (`io.h`). Bandwidth,
    spreading factor, coding rate and TX power are **not** set anywhere, so the radio runs the
    Sandeep Mistry library defaults: **SF7, 125 kHz, CR 4/5, 17 dBm, sync word `0x12`**. This entry
    used to claim full runtime configuration of all of those, which was never true of any node — a
    reader sizing an airtime budget or chasing a range problem would have gone looking for tuning
    that does not exist. SF7/125 kHz is where the ~195 ms of channel occupancy per `TOPDATA` frame
    comes from, which is why the Top throttles telemetry while station keeping.
*   **The band is a compile-time `#define`, repeated in three files that must agree**:
    `RoboLora/src/io.h`, `RoboTop/src/loratop.h` (both `LoRa_frequency`) and
    `RoboCYD/src/cyd_lora.cpp` (`LORA_BAND`). There is no shared header and no runtime setting, so
    changing band means editing three places and reflashing everything; miss one and that node goes
    silent without an error — it will transmit and receive perfectly happily, just nowhere anyone
    is listening. The CYD prints `LoRa: 433M` on its boot screen, which is the quickest confirmation
    of what a handheld is actually running.
*   **Hardware CRC is enabled on all three** (`LoRa.enableCrc()`). It has to be enabled or disabled
    fleet-wide: a receiver expecting a CRC will drop every frame from a transmitter that does not
    append one.
*   **Asynchronous Polling**: Runs an optimized FreeRTOS background task to monitor the LoRa FIFO buffer, raising real-time interrupts upon packet arrivals to prevent buffer overflows.

### 1b. The gateway is a first-class node on the air

RoboLora does not only relay. It **reports its own link quality** (`LORA_LINK`, cmd 94, once a
minute) and it **repeats** for others, so it transmits under its own ID like any buoy. Worth knowing
because it is by some margin the strongest transmitter on the network — measured at the two Tops it
arrives at -76 and -83 dBm against a handheld's -102 and -103 — which is exactly why standing it
near a weak node is useful, and exactly why the repeater was added.

#### The repeater

RoboLora had **no** repeater until recently, so standing the gateway near a weak node did nothing
for anybody but the gateway. It has one now, ported from RoboTop with the same constants
(`REPEATER_CACHE_SIZE` 16 / `REPEATER_TIMEOUT_MS` 20 s, `REPEAT_SLOTS` 4, `REPEAT_NODE_SLOTS` 5,
`REPEAT_SLOT_MS` 250, `REPEAT_BASE_MS` 40, `REPEAT_JITTER_MS` 60, `REPEAT_EXPIRY_MS` 3000) — they
must stay equal across firmwares, because the slot budget is sized against the *sender's* retry
interval and the sender may be any node.

**The full explanation of the mechanism, and of why each rule exists, is in the RoboTop README
(§2b).** In short: a frame addressed to somebody else is relayed in case that somebody is out of the
sender's range but in ours; unicast only, because relaying broadcast telemetry once measured at
~195% channel occupancy and starved the traffic that mattered; `LORA_LINK` is the one broadcast
exception, because a link report's entire purpose is to arrive from a node you cannot hear directly;
a 20 s verbatim dedup cache stops it circling; relays are deferred into per-MAC slots so two nodes
never transmit at the same instant; and a queued relay is cancelled the moment the frame is heard
from anyone else, so only the lowest-slot node in range actually spends the airtime.

Why it is worth having *here* in particular: measured at the two Tops, the gateway arrives at -76
and -83 dBm against a handheld's -102 and -103. It is the strongest transmitter on the network, so
it is the most useful relay on it.

> **Consequence for everything that consumes frames.** A `LORA_LINK` sender is *not* necessarily a
> buoy. Once the gateway started reporting, every consumer that registered "any sender with a
> plausible ID" gave it a buoy slot — it appeared in the CYD's three-slot menu and in the web
> dashboard's panels with no position, no heading and nothing to steer, and it displaced something
> that had all three. Both were fixed at the reading end: only `TOPDATA` and `BUOYPOS` prove a
> sender is a buoy. Anything new that parses this protocol must apply the same rule.

### 2. Local OLED Diagnostic Screen (`oled_ssd1306.cpp` / `oled_ssd1306.h`)
*   **Hardware Interface**: Drives a localized monochrome SSD1306 OLED screen over I2C.
*   **Live Status Monitoring**: Displays vital real-time diagnostics including:
    *   Last received packet payload summary.
    *   Transceiver signal health: **RSSI** (Received Signal Strength Indication) and **SNR** (Signal-to-Noise Ratio).
    *   Local battery voltages (measured via internal ADC).
    *   System operational state markers.

### 3. USB-to-UART Bridging (`sercom.cpp` / `sercom.h`)
*   **High-Speed Uplink**: Implements a high-baudrate (115200bps) UART-to-USB bridge that streams decoded ASCII comma-separated packages directly into the host PC's operating system.
*   **Control Reception**: Translates downstream command strings originating from the desktop Python dashboard and packages them into target-specific LoRa transmission frames.

### 4. Advanced Web-Based Control Panel (`data/` / `controlwifi.cpp`)
*   **Priority list**: `NicE_WiFi` (password `!Ni1001100110`) then `Robo_WiFi` (password
    `geenanker`) then its own **`LORA_<id>`** AP (password `geenanker`, `192.168.4.1`). No scanning:
    the SSIDs are tried in order with a blind `WiFi.begin()`.
*   **RoboLora is a client of the field network, not its host.** It used to raise the field AP
    itself under the same name the CYD uses; two devices broadcasting one SSID on one subnet is two
    separate networks wearing the same badge, and the fleet would split between them. **The CYD is
    the field AP** - see [RoboCYD](../RoboCYD/README.md).
*   **The fallback AP keeps hunting.** It runs in `WIFI_AP_STA` and keeps looking for a real network
    underneath, but will not tear itself down while a client is connected.
*   **mDNS**: reachable as `lora-<id>.local` in both modes. Only `ArduinoOTA.begin()` may initialise
    the responder.
*   **Captive Portal & DNS Redirection**: a `DNSServer` on UDP port 53 resolves every lookup to our
    own AP address while we are the access point, so a phone's connectivity probe lands on the
    dashboard and the "sign in to network" sheet opens it automatically. The 302 for unknown URLs is
    aimed at `WiFi.softAPIP()` - it used to be hardcoded to `192.168.1.84`, which was the Top's old
    AP address rather than ours - and it is **disabled when we are a station**, where a 404 must stay
    a 404 or a mistyped fetch silently returns the whole dashboard.
*   **Sender identity**: every frame RoboLora puts on UDP is stamped `IDs = 0x99`, the web-authority
    ID. Buoys act on broadcast commands only from `0x99` (web/RoboLora) and `0x98` (the CYD), so this
    stamp is what makes operator commands authoritative - and why it must not be applied to traffic
    merely being relayed.
*   **Intuitive Dashboard Interface**: Serves a highly customized HTML5 dashboard (`index.html`, `index.js`, `style.css`) from the local SPIFFS partition over an integrated Wi-Fi Access Point or Local Station.
*   **Dual-Source Telemetry Prioritization**: Real-time client-side filter prioritizes high-speed UDP Wi-Fi data (updating fluidly at **250ms** intervals) and ignores slower, redundant LoRa packets (still logged in their respective consoles) to eliminate UI lag or gauge flickering.
*   **Responsive Dual-Column Configuration Popup**: Restructured the setup modal into a dual-column layout on wider screens, placing Speed PID vertically under Rudder PID, and featuring highly legible, enlarged labels and values in bold blue monospace. Includes:
    *   Interactive **Set as North** auto-offset calibration based on the buoy's live heading.
    *   Rudder and Speed PID coefficients, speed limits, battery boundaries, and motor option toggles (motor swapping, reverse BB/SB).
*   **Isolated WebSockets Logging**: WebSocket messages are prefixed with `LORA:` and `UDP:` to safely route incoming radio traffic and local network broadcasts to separate browser monitors without console pollution.

### 5. Transmission Safety & Loop Protections (`main.cpp` / `sercom.cpp`)
*   **Telemetry Feedback Loop Prevention**: Patched a firmware bug in `fillBuoyArr` where newly discovered buoys copied telemetry directly without clearing active `cmd`/`ack` properties. This now guarantees the system does not get locked in infinite re-transmission loops of stale command packets.
*   **Serial Commands-Only Forwarding Filter**: Configured `SercomTask` (`src/sercom.cpp`) to only forward actual commands (`GET`, `SET`, `GETACK`) from the USB Serial line to the LoRa radio. It successfully discards passive, high-frequency telemetry, preventing radio channel saturation, saving battery, and allowing local Wi-Fi scan threads to execute seamlessly without timeouts.

---

## 🛠️ Building & Flashing

RoboLora is managed via the **PlatformIO** ecosystem:

Environment **`pico32`**. Libraries include `RoboCompute`, `Adafruit_SSD1306` and `RoboTone`.

```bash
pio run                  # build
pio run -t upload        # serial upload, upload_port = COM30
```

**There is no espota configuration**, and `COM30` may not exist on the machine you are using. The
gateway does run ArduinoOTA, so flash it over the network directly:

```bash
python ~/.platformio/packages/framework-arduinoespressif32/tools/espota.py \
       -i <ip> -p 3232 -f .pio/build/pico32/firmware.bin -r
```\n

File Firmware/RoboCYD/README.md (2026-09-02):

# RoboCYD — Touchscreen Fleet Controller and Field Access Point

The **`RoboCYD`** firmware runs on a "Cheap Yellow Display" board: an ESP32 with a 320×240 TFT and a resistive touch panel. It is the handheld controller for the fleet — it shows every buoy, sends lock/dock/idle commands, and serves a web dashboard and a fullscreen map.

It also has a second job that nothing else does: **out on the water, the CYD *is* the network.**

---

## 🌐 The CYD is the field access point

Every node follows the same priority list, but the CYD sits at the top of it:

| Device | Priority list | In the field |
|---|---|---|
| **RoboCYD** | `NicE_WiFi` → **becomes `Robo_WiFi`** | the field AP |
| RoboTop | `NicE_WiFi` → `Robo_WiFi` → `TOP_<id>` | joins the CYD |
| RoboSub | `NicE_WiFi` → `SUB_<id>` | always its own AP |
| RoboLora | `NicE_WiFi` → `Robo_WiFi` → `LORA_<id>` | joins the CYD |

*   At home the CYD joins `NicE_WiFi` like everything else.
*   When no `NicE_WiFi` is in reach it raises **`Robo_WiFi`**, password **`geenanker`**, on
    **`192.168.1.1/24`** — the same subnet as home, so the field network and the living room look
    identical from a browser. The AP is its own gateway; advertising a gateway that never answers
    makes Android decide the network is broken and drop it.
*   **8 client slots.** The Arduino default of 4 is exactly three Tops plus a phone, leaving nothing
    for a laptop. The ESP32 silicon allows 15.
*   **The Sub deliberately does not join**, keeping those slots for the Tops and a phone.

### It decides once, at boot
Migrating back to home mid-session would tear `Robo_WiFi` out from under every Top at once. So the
CYD re-checks for home **only while nobody is connected to it** — the "carried everything indoors"
case. With a Top attached it stays put.

### Getting in without an IP
*   **Captive portal** while it is the AP: wildcard DNS on port 53 means a phone's own connectivity
    probe lands on the dashboard and the "sign in to network" sheet opens it unprompted. The 302 is
    aimed at the real softAP address, and is **off** when the CYD is a station — there, a 404 must
    stay a 404.
*   **mDNS**: `robocyd.local`, in both modes. Only `ArduinoOTA.begin()` may initialise the
    responder; a second `MDNS.begin()`, or an `MDNS.end()` while OTA holds it, has crashed this
    hardware. Add records with `MDNS.addService()` on top of the one OTA created.

---

## ⚡ Core modules

### `cyd_lora.cpp` — radio on its own task

**433 MHz** (`LORA_BAND`), library defaults otherwise — SF7, 125 kHz, CR 4/5, hardware CRC enabled
to match the rest of the fleet. The band is `#define`d here rather than shared, and the same figure
is repeated in `RoboTop/src/loratop.h` and `RoboLora/src/io.h`; all three must agree or the odd one
out goes quietly deaf. The boot screen prints `LoRa: 433M`, which is the fastest way to check what a
handheld is actually running.

The radio is drained by a **dedicated FreeRTOS task**, not from `loop()`.

`loop()` also runs OTA, the web server and every screen repaint, and a full redraw pushes enough
pixels over SPI to take far longer than one packet is on the air. The Tops send `BUOYPOS`
immediately followed by `TOPDATA`, so the radio must be read twice inside ~130 ms — and the draw
loop was not coming back that fast. The second frame of every pair was overwritten before it was
ever read: a buoy sending them one for one showed up here as **12 `BUOYPOS` and 0 `TOPDATA` per
minute**.

The task does nothing but move bytes off the radio into a queue. Parsing stays on the main loop, so
`buoys[]` keeps a single writer and the Arduino `String`s inside it are never reallocated under the
draw code. A **mutex guards every SX127x access**, because the task polls continuously while
`send_lora_packet()` is called from the touch handlers on the other core, sharing one SPI bus and
one radio.

### `buoy_data.cpp` / `.h` — fleet state
Holds up to three buoys: identity, position, heading, battery, status, RSSI and link freshness.

Buoys also carry **the waypoint they were told to hold**, taken from `LOCKPOS`/`DOCKPOS` (cmd 21/23)
— the only frames that carry it. `TOPDATA` and `BUOYPOS` say where a buoy *is*, never where it is
meant to be. It ages out on a timestamp (`buoy_has_waypoint()`), because a Top stops beaconing the
moment it leaves `LOCKED`/`DOCKED`, and a stale mark on the plot is worse than no mark.

**Only real telemetry claims a slot.** There are three, and `LORA_LINK` (94) is answered and
returned from before the slot search ever runs. A link report says what a node *hears*; it does not
say the node is a buoy. RoboLora reports its links like everybody else, and while every sender was
eligible the gateway walked into a slot and sat there — a row in the menu with no heading, no
position and nothing to steer, and one fewer slot for something that has all three. Nothing is lost
by refusing it: a node that is also a buoy is registered by its own `TOPDATA`/`BUOYPOS` anyway.

**The Setup screen owns its fields while it is open.** `buoys[]` is not only the fleet model, it is
also the Setup screen's edit buffer — there is no separate copy — so an incoming `SETUPDATA` lands
directly on unsaved work. And one arrives constantly: RoboTop re-reads the Sub's settings every
`SUB_SETUP_RESYNC_MS` (20 s) and broadcasts the answer to `BUOYIDALL` on both transports, asked for
or not. That poll is right in itself, and it was written against the *web* dialog, which fills its
fields once on open and is genuinely safe from it. This screen reads `buoys[]` live, so it was not:
values dialled in on `+`/`-` reverted a few seconds later, and Set as North's computed offset was
replaced by the buoy's old one before SAVE could send it. Once the screen has its initial load the
parser leaves those fields alone until it is left; entering Setup clears `setup_data_loaded` and
re-asks, so they are still fresh every time it opens. `setup_await_refresh` lets exactly one reply
through afterwards, for the case below. Telemetry is untouched — it is not edited, and the screen
needs it live.

### `main.cpp` — screen and menu
*   Menu buttons are laid out to the button edges rather than centred, so a full
    `Buoy n: b7a5b578` fits beside a one-character status badge.
*   A button is repainted **only when the ID, presence, IP or status changes**. RSSI is deliberately
    kept out of that cache key: it moves with every packet and would repaint the whole 40 px button
    at packet rate, which is the flicker the caching exists to prevent. It gets its own small
    repaint.
*   The status badge is `I` idle, `L` locked, `D` docked. `LOCKING`/`DOCKING` report the letter they
    are heading for but are flagged unsettled — a buoy that cannot get a GPS fix sits in `LOCKING`
    indefinitely, and a plain `L` there would claim it is holding station when it has not started.
*   A waypoint further from the fleet than a sane course mark is **pegged to the rim** rather than
    stretching the plot until the buoys are unreadable.

### Setup actions the **buoy** performs

Set as North used to be arithmetic done here: `compass_offset - mag_dir` written into `buoys[]`,
followed by a jump to the compass page and a wait for SAVE. It sent nothing. That failed three ways
at once — the value was overwritten by the resync described above, it needed a SAVE the operator had
to know to press, and the page jump is what "it jumps to another screen" meant. Underneath all of it
the formula was the superseded one: the Sub retired `compassOffset - dirMag` because it took three
or four presses to creep onto north, which is exactly what pressing the button repeatedly looks
like.

It now sends **`SET_AS_NORTH` (87)** — the same command the Top's web page sends. The Sub solves it
with `computeSetAsNorthOffset()`, which reads the heading out of the pipeline *after* the compass
table and the trim and lands on north in one press, commits it to its own NVS and beeps. RoboTop
re-reads the setup immediately (`requestSubSetup("after SET_AS_NORTH")`) and that reply is the one
`setup_await_refresh` admits, so the new offset appears on the compass page by itself. Nothing to
save, no page jump, and one implementation of the solve instead of two.

Set as Level (`SET_AS_LEVEL`, 93) already worked this way and is unchanged. The rule for this page
is now uniform: **if the buoy owns the value, the buoy computes it.**

### Wind is both ends of the line

Port and starboard used to be decided by `pick_wind_reference_buoy()` — the first buoy in the list
with a non-zero reading, i.e. whichever one happened to be there. Two anemometers a line's length
apart disagree by a few degrees in steady air and by rather more in a shifty one, and there is no
reason to prefer either.

`start_line_wind()` returns the **mean of what the two line-end buoys report**, found via
`find_start_line_pair()` — the closest pair, measured where they actually are. With three buoys the
upwind mark is left out: it is no part of the line. `mean_wind_dir()` is a vector mean, not an
arithmetic one, or 350° and 10° would average to 180° instead of 0°. A buoy reading 0/0 has no
reading rather than a northerly, so it drops out and the other end is used alone.

The wind **label** now comes from the same place as the geometry. Showing one buoy's reading beside
a line squared to a different figure is how an operator stops trusting both. The spread printed next
to it is the *worse* of the two, not their mean — it is a confidence figure, and two readings do not
make a shifty wind steady.

The same solve exists in three places on purpose, and they have to stay in step: `meanWindDir()` in
RoboCompute for the squaring the Top actually performs, `mean_wind_dir()` here, and
`mapMeanWindDir()` in `index.js`.

### `cyd_wifi.cpp` — web, WebSocket and UDP
*   Serves `index.html`, `index.js`, `style.css` from SPIFFS, plus a **standalone fullscreen map**
    in its own tab with an independent redraw loop and a canvas sized to the window.
*   **WebSocket on port 81** relays everything the CYD hears to the browser, prefixed `LORA:` or
    `UDP:` so radio and network traffic stay in separate consoles. This is also the easiest way to
    watch LoRa traffic from a PC — the CYD is the only node that rebroadcasts it.
*   **UDP 1001** for protocol frames.
*   Commands typed by the browser are forwarded **verbatim** to both LoRa and UDP; the CYD does not
    stamp IDs. The web UI builds the whole frame, addressing it to a specific buoy with sender `99`
    (hex `0x99`).

#### The web map had to be taught what the screen already knew

The dashboard map and the touchscreen map disagreed, and the touchscreen was right. Three reasons,
all now fixed in `index.js`:

*   **It never read the waypoint.** `LOCKPOS`/`DOCKPOS` are the only frames carrying a set point as
    coordinates, and the page had no handler for either despite defining the enum. It reconstructed
    each waypoint by projecting `Target Dir`/`Target Dist` off the buoy's own fix — and that
    reconstruction is refused when the reported distance is 0, which is exactly what a buoy that has
    *arrived* reports. So the moment the fleet settled on station every waypoint vanished and the
    map fell back to measuring between two hulls wandering inside their hold radius. It now records
    the real coordinates and ages them out on the same 20 s window the firmware uses, deliberately
    the same figure so the two views drop a stale mark together. Projection survives only as a
    fallback before a waypoint frame has been heard.
*   **The line is drawn between the hulls.** That is what the crew can see from the water, and what
    the touchscreen always drew. The *figure* beside it is still measured off the two waypoints
    where both ends have one — the dots wander, the waypoints do not, and EXECUTE has to be able to
    put the line back where it was but longer. Without both waypoints the length still shows and
    `-`/`+`/EXECUTE grey out rather than firing on a target that cannot be computed.
*   **The gateway took a panel.** Same defect as in the firmware, same fix: only `TOPDATA` and
    `BUOYPOS` prove a sender is a buoy. RoboLora has no fix so it never reached the map itself, but
    it did occupy one of three slots.

#### No confirmation dialogs

All five `confirm()` popups are gone. A modal in the middle of a field job is the worst place for
one, and each was guarding something that did not need it: EXECUTE is already the deliberate second
step after dialling a length in and stays greyed out until the figure differs; re-capturing a
calibration leg writes nothing until CLOSE and is the normal way to *fix* a bad reading, so the
dialog blocked the recovery rather than the mistake; discarding a run loses nothing, as the dialog
itself said; the desk calibration's instructions belong on the page beside the button, not behind a
dismissal; and a reboot loses nothing because every setting is in NVS. What happened is still
reported — after the fact, in the map message and the log, rather than in the way.

> A caveat worth knowing: `index.js`'s `handleJsonFallback()` contains
> `b.id = b.id || "0001"`, and `"0001"` parses as hex `1` — which **is** `BUOYIDALL`. A command sent
> to a buoy carrying that fallback ID would go to the whole fleet. The path is currently dormant
> (it needs a non-`$` JSON message the CYD never sends), but `"0001"` is a poor sentinel for
> "unknown buoy".

### `boot_screen.cpp` — splash
Draws `data/boot_logo.565` at startup. The logo is generated by `tools/make_boot_logo.py`; the LVGL
reference it was derived from is under `Doc/robobuoy_startup_lvgl_reference/`.

### `cyd_touch.cpp`, `cyd_display.cpp`, `RGBledDriver.cpp`
Resistive touch (XPT2046), TFT_eSPI display setup, and the onboard RGB LED.

---

## 🛠️ Building & Flashing

Environment **`cyd`** (`board = esp32dev`, `platform = espressif32@6.5.0`). Note
`src_dir = .` with `build_src_filter = +<src/>`. Libraries: `TFT_eSPI`, `XPT2046_Bitbang_Slim`,
`lvgl`, `LoRa`, `WebSockets`.

```bash
pio run                  # build
pio run -t upload        # serial upload, upload_port = COM15
pio run -t uploadfs      # required after any data/ change
```

**There is no espota configuration**, and `COM15` may not exist on the machine you are using. The
CYD does run ArduinoOTA, so flash it over the network directly:

```bash
python ~/.platformio/packages/framework-arduinoespressif32/tools/espota.py \
       -i <ip> -p 3232 -f .pio/build/cyd/firmware.bin -r
```

`monitor_filters = esp32_exception_decoder` is already set, so a panic on this board prints a
decoded backtrace with function names — worth remembering, because the CYD is the one node normally
reachable over USB.

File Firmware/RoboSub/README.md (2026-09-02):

# RoboSub — Autonomous Marine Buoy Subunit Firmware

The **`RoboSub`** firmware runs on the submerged ESP32 microcontroller of the NicE-Buoy Autonomous Marine System. Acting as the low-level physical execution and navigation engine, it processes raw sensor data, executes autonomous PID navigation loops, and drives the thrusters via Electronic Speed Controllers (ESCs).

---

## 🏗️ Subsystem Architecture & FreeRTOS Flow

RoboSub utilizes FreeRTOS to manage real-time tasks across the dual cores of the ESP32:
*   **Core 1 (High-Priority Navigation & Sensors)**: Processes timing-critical I2C sensor fusion (`CompassTask`), 100Hz PID locomotion loops (`EscTask`), and single-wire serial bridge decoding (`SercomTask`). This guarantees isolated, high-precision timing away from Wi-Fi overhead.
*   **Core 0 (Communications & Visuals)**: Manages Wi-Fi networking client hooks (`WiFiTask`), addressable LED status animations (`LedTask`), and status buzzer audio signals (`buzzerTask`).

```
┌────────────────────────────────────────────────────────────────────────┐
│                                RoboSub                                 │
├───────────────────────────────────┬────────────────────────────────────┤
│              Core 0               │               Core 1               │
├───────────────────────────────────┼────────────────────────────────────┤
│ - WiFiTask (Local AP Web Server)  │ - CompassTask (ICM-20948 Fusion)   │
│ - LedTask (NeoPixel Animations)   │ - EscTask (100Hz PID Loco Loops)   │
│ - buzzTask (Audio Sounder Beeps)  │ - SerialTask (single-wire bridge)  │
└───────────────────────────────────┴────────────────────────────────────┘
```

```
                      ┌────────────────────────────────────────┐
                      │             RoboTop (UART)             │
                      └───────────────────┬────────────────────┘
                                          │ one wire, half duplex
                                          ▼
                      ┌────────────────────────────────────────┐
                      │               SercomTask               │
                      │       - Decodes Command Frames         │
                      │       - Single-wire Echo Filter        │
                      └───────────────────┬────────────────────┘
                                          │
                  ┌───────────────────────┼────────────────────────┐
                  │ Queues / Mutex        │ Queues / Mutex         │ Queues
                  ▼                       ▼                        ▼
┌────────────────────────────────┐ ┌────────────────────────┐ ┌────────────────────────┐
│           CompassTask          │ │        EscTask         │ │        LedTask         │
│  - ICM-20948 I2C Fusion (69/68)│ │  - Rudder + speed PID  │ │  - Status NeoPixels    │
│  - Madgwick AHRS Filter (100Hz)│ │    (pidrudspeed.cpp)   │ │  - Battery Telemetry   │
│  - 3D Copilot Web Calibration  │ │  - Differential mix    │ └────────────────────────┘
└────────────────────────────────┘ │  - Port (BB) / Stbd(SB)│
                                   └────────────────────────┘

     There is no separate PIDTask. The loops live in pidrudspeed.cpp and are
     driven from EscTask, which also writes the ESC duty cycles.
```

---

## ⚡ Core Modules & Functionality

### 1. Locomotion & Thruster Mixing (`esc.cpp` / `esc.h`)
RoboSub translates abstract navigation instructions into physical locomotion using differential thrust mixing:
*   **Hardware Interface**: Controls two brushless thrusters—**Port (BB)** and **Starboard (SB)**—via electronic speed controllers connected to hardware PWM channels utilizing the `ESP32Servo` library.
*   **Arming Sequence**: Executes a strict ESC arming cycle at boot (writing a safety-neutral 1500µs pulse-width) to protect hardware and ensure pilot safety.
*   **Differential Thrust Mixer**: Combines the forward speed demand ($PID_{\text{speed}}$) and steering demand ($PID_{\text{rudder}}$) to drive both motors independently:
    $$Thrust_{\text{Port}} = Speed + Steering$$
    $$Thrust_{\text{Starboard}} = Speed - Steering$$

### 2. High-Performance ICM-20948 Compass & Madgwick Fusion (`compass.cpp` / `compass.h`)
RoboSub utilizes a high-performance **ICM-20948 9-DOF IMU** coupled with a mathematical **Madgwick AHRS sensor fusion filter** to compute highly precise, drift-free magnetic headings.

*   **I2C Auto-Discovery**: Automatically probes active I2C addresses `0x69` and `0x68` at boot, dynamically instantiating the driver object on the discovered port.
*   **Zero-Rate Gyro Bias Calibration**: Runs an automated 200-sample gyroscope calibration routine at boot to calculate static offsets, ensuring gyro drift is eliminated.
*   **Advanced Madgwick AHRS Fusion (100Hz)**: Feeds filtered, low-passed accelerometer, gyroscope, and aligned calibrated magnetometer readings into a 100Hz Madgwick AHRS algorithm to track roll, pitch, and yaw.
*   **Active Calibration & Fusion Modes (`icm_mode`)**: Users can dynamically select between four mathematical fusion modes on the web panel depending on operational conditions:
    *   **Mode 1: Only Hard Iron (No Soft, No Tilt)**: Applies simple hard-iron offsets ($hi_{x,y,z}$) to center the magnetic sphere back to $(0,0,0)$ on the local 2D plane. Ideal for basic diagnostic checks.
    *   **Mode 2: Hard & Soft Iron (No Tilt)**: Applies both centering offsets and soft-iron scaling matrices ($si_{x,y,z}$) to deform the magnetically squeezed ellipsoid back into a perfect sphere. Assumes the buoy remains physically level (flat-water).
    *   **Mode 3: Hard Iron & Pitch + Roll (No Soft)**: Applies centering offsets and standard 3D trigonometric pitch ($p$) and roll ($r$) tilt-compensation. Recommended if soft-iron calibration is uninitialized but the buoy is rocking.
    *   **Mode 4: Hard & Soft Iron & Pitch + Roll (Default)**: The most advanced mode. Combines 3D hard-iron offsets, soft-iron scaling, and live geometric pitch and roll projections to calculate extremely precise headings even during severe angular tilting in turbulent seas.
*   **Tilt-Compensated Magnetometer Math**: When Mode 3 or 4 is active, the system calculates the pitch ($p$) and roll ($r$) vectors from the low-passed accelerometer and projects the 3D magnetometer readings back onto a virtual horizontal plane:
    $$X_h = m_x \cos(p) + m_y \sin(r)\sin(p) + m_z \cos(r)\sin(p)$$
    $$Y_h = m_y \cos(r) - m_z \sin(r)$$
    This resolves the exact heading as: $\text{Heading} = \text{atan2}(Y_h, X_h) \times \frac{180}{\pi}$.
*   **NVS Persistence & Hard/Soft Iron Scaling**: Loads custom 3D calibration matrices (Hard Iron: `hi_x`, `hi_y`, `hi_z`; Soft Iron: `si_x`, `si_y`, `si_z`) from persistent Preferences NVS (Flash) to scale and offset raw magnetic distortion.
*   **3D Copilot Interactive Calibration Web Dashboard**:
    *   Integrates an interactive **3D Compass Calibration Tool** served via HTTP from the ESP32.
    *   Features real-time 3D plotting and feedback to help operators execute figure-eight and pitch/roll movements (Z-span checking) in the field.
    *   Validates point count (minimum 500 points) and multi-axis coverage before letting users commit the calculated parameters directly to NVS, playing an audio cue upon successful calibration storage.
*   **Highly Stable Averaging Filter**: Runs heading outputs through a low-pass Exponential Moving Average (EMA) filter and caches them into a 25-step circular averaging buffer (`NUM_DIRECTIONS 25`), smoothing out MEMS noise and momentary magnetic anomalies caused by high-power thruster surges.

### 3. Dual-Loop PID Navigation (`pidrudspeed.cpp` / `pidrudspeed.h`)
Autonomy is governed by independent, high-speed PID loops running at **100Hz** in `pidrudspeed.cpp`, driven from `EscTask`:
*   **Speed PID**: Computes the required thrust based on the remaining distance to the target waypoint.
*   **Rudder PID**: Calculates the required heading correction to align the buoy's current heading with the target direction.
*   **Navigation Modes**:
    *   `IDLE`: Thrust output disabled; motors neutral.
    *   `MANUAL`: Bypasses PID control to allow direct manual piloting over LoRa or WiFi.
    *   `LOCKED`: Autonomous position-holding (GPS Anchor) using localized coordinate boundaries.
    *   `DOCKING`: Automated waypoint navigation to guide the buoy to its charging station or home harbor.

### 4. UART Serial Interface (`sercom.cpp` / `sercom.h`)
RoboSub communicates with the `RoboTop` over **one shared wire**, half duplex, with hardware
separating the two directions (opto-isolated). Sub **RX 5 / TX 18**, Top **TX 22 / RX 21** - two
GPIOs per board, but not two conductors.

> **Diagnostic consequence:** a bad connector or wire stops traffic in *both* directions. A failure
> in **one direction only** is in the direction-separation circuitry, which is per board. Swapping
> the Sub between hulls localises such a fault to a specific board - that is how a dead receive
> side was traced to one Sub rather than to its Top or the cable.

*   **Half-Duplex Echo Filtering**: Because the RX and TX lines are tied together, the transmitting ESP32 receives its own transmissions. `SercomTask` filters out these loopback echoes by comparing the sender MAC address against its own address, discarding self-transmitted frames automatically.
*   **Implicit Acknowledgments**: Every periodic `INF` telemetry response from RoboSub serves as an implicit acknowledgment for commands, which reduces communication overhead and prevents packet congestion.

### 5. Wi-Fi Connectivity & Dashboard Web Server (`subwifi.cpp` / `subwifi.h`)
RoboSub hosts a lightweight local web server to display real-time telemetry diagnostics and host the interactive 3D compass calibration tool:

*   **Priority list**: `NicE_WiFi` (password `!Ni1001100110`) then its own **`SUB_<id>`** AP
    (password `geenanker`, `192.168.4.1`, captive portal). No scanning - the SSID is tried directly
    with a blind `WiFi.begin()`, because a scan blocks for seconds and drags the single radio off
    the AP channel.
*   **The Sub deliberately skips `Robo_WiFi`**, the CYD's field AP, to keep its client slots for the
    Tops and a phone. Nothing is lost by this - see below.
*   **Home is tried once, at boot.** If `NicE_WiFi` is not in reach the Sub raises `SUB_<id>` and
    stays on it until the next reboot - no periodic re-hunting. The old build retried every 45 s,
    and because the ESP32 has one radio each attempt pulled it off the AP's channel for up to 15 s,
    so the `SUB_<id>` AP kept vanishing from the phone's WiFi list and coming back. A Sub that *did*
    join home at boot still re-joins if the link drops, but the first re-join that fails raises its
    own AP and ends the hunt for good. To get back onto `NicE_WiFi`, power cycle.
*   **mDNS**: reachable as `sub-<id>.local` in both modes. Only `ArduinoOTA.begin()` may initialise
    the responder - a second one has crashed this hardware.
*   **The Sub never transmits on UDP.** The broadcast in the WiFi loop is commented out, and the
    `udpIn` queue is filled but never drained, so no UDP command reaches the handler either. All of
    the Sub's telemetry reaches you folded into the Top's `TOPDATA`, heading and battery included.
*   **Web Services**: `/data` (JSON telemetry) and `/params` (stored tuning), plus the compass
    calibration endpoints.
*   **Debug channel**: plain text on **UDP 1002**, silent at idle. Prints `SER in cmd=..` for every
    frame arriving on the serial link - the quickest way to prove whether the Sub's receiver works
    without opening the hull.

### 5b. Power-down behaviour
After reconnection the Sub sits in **power-down** and only wakes on an incoming command: send one,
wait, then it communicates. Do not read a quiet Sub as a fault until it has been nudged. It is
awake, though, if it is answering - a Sub that acknowledges several commands while its Top still
reports `SubOk=false` is a real one-way break, not sleep.

### 5c. The Sub owns the tuning
Every parameter in the NVS section below lives here. The Top holds a RAM copy only, fetched with
`SETUPDATA` when the serial link comes up. **`compassOffset`, `revBB`, `revSB` and `swap_BB_SB` are
hull-specific** - they describe the physical boat, not this board - so moving a Sub to another hull
carries the wrong values with it until they are re-entered.

### 5d. Set as North belongs to the buoy

`SET_AS_NORTH` (87) is solved here and nowhere else, by `computeSetAsNorthOffset()`: it takes the
heading out of the pipeline *after* the compass table and the trim, negates it, and stores the
result as `compassOffset` in NVS. Absolute, not incremental — it does not read the previous offset —
so pressing it twice is idempotent and a command delivered over both LoRa and UDP does no harm.

That absoluteness is the point. The retired `compassOffset - dirMag` needed three or four presses to
creep onto north; this lands on it first time. The handheld carried a copy of the old formula until
recently and did its own arithmetic locally, which is why Set as North worked from the Top's web
page and not from the CYD. Both now send the command and let the buoy answer it. **Do not
re-implement this solve at the sending end** — the offset depends on the state of the table and the
trim, which only the Sub knows.

`SET_AS_LEVEL` (93) follows the same rule for the attitude datum.

> `main.cpp`'s command filter accepts **any** `SETUPDATA` regardless of addressing
> (`|| dataIn.cmd == SETUPDATA`). Harmless while the Sub has no UDP input path, but worth
> remembering before one is added.

---

## 🎛️ Peripheral Controllers

*   **Battery Telemetry (`adc.cpp`)**: Reads battery voltages via ESP32 ADC pins, applies smoothing filters to eliminate voltage sags from thruster surges, and logs the cell power telemetry.
*   **Sounder Feedback (`buzzer.cpp`)**: Drives a piezo sounder, emitting audible frequencies and beep sequences to signal boot status, profile loading status, and save actions.
    *   **A save now chirps (`beep(6)`, 2000 Hz for 80 ms).** A save made during a calibration
        happens with somebody stood over the hull and nowhere near a screen, so "did that take?" is
        a question only the buoy can answer. Fired after the `MEM_PUT`s and the reload, so it means
        the values are in NVS rather than that a frame arrived — and **debounced at one second**,
        because a SAVE goes out on LoRa *and* UDP and the Top forwards both copies a few hundred
        milliseconds apart. Two chirps for one press would read as two saves.
    *   **Its own tone, not a reuse.** Every neighbour already means something: `10` is the
        button-press tick, `1` the rising tune for a computation that produced a result, `5` the
        compass-table tune, `-1` failure.
    *   **`SET_AS_NORTH` was playing `beep(-1)` on success** — the failure tone, the one a buoy plays
        when a start line cannot be computed. It stores the compass offset in NVS, so it plays the
        save chirp now. The same mix-up had already been found and fixed in `subwifi.cpp`; a good
        save has to sound like one, or the operator learns to ignore the buzzer altogether.
*   **Visual Status Matrices (`leds.cpp` / `leds.h`)**: Displays system states, communication connectivity, and battery low warnings via an addressable WS2812B RGB NeoPixel array.

---

## ⚙️ Persistent Configuration Parameters (Preferences NVS)
RoboSub utilizes the ESP32's **Preferences NVS (Non-Volatile Storage)** to store and load operational parameters across power-cycles. This ensures all controller configurations remain persistent:

### 1. Autopilot PID Parameters
*   **Rudder / Steering PID (`Kpr`, `Kir`, `Kdr`)**:
    *   `Kpr` (Default: `1.0`): Proportional coefficient for steering correction.
    *   `Kir` (Default: `0.0`): Integral coefficient.
    *   `Kdr` (Default: `0.0`): Derivative coefficient (steering damping).
*   **Speed / Approach PID (`Kps`, `Kis`, `Kds`)**:
    *   `Kps` (Default: `1.0`): Proportional coefficient for waypoint distance approach.
    *   `Kis` (Default: `0.0`): Integral coefficient.
    *   `Kds` (Default: `0.0`): Derivative coefficient.

### 2. Differential Locomotion Limits & Motor Flags
*   **Thrust Boundaries (`maxSpeed`, `minSpeed`, `pivotSpeed`)**:
    *   `maxSpeed` (Default: `75`): Maximum forward speed percentage allowed under autonomous control.
    *   `minSpeed` (Default: `-75`): Maximum reverse speed percentage allowed under autonomous control (NVS initializer writes `-75`).
    *   `pivotSpeed` (Default: `0.2`): Proportional motor speed coefficient during in-place pivoting.
*   **Thruster Correction Flags (`revBB`, `revSB`, `swap_BB_SB`)**:
    *   `revBB` (Default: `false`): Boolean flag to invert the rotation direction of the Port (BB) thruster.
    *   `revSB` (Default: `false`): Boolean flag to invert the rotation direction of the Starboard (SB) thruster.
    *   `swap_BB_SB` (Default: `false`): Boolean flag to swap Port and Starboard output control channels (remedies physical ESC wire cross-overs).

### 3. Compass Calibration & Correction Math
*   **Mounting Alignment (`compassOffset`)**:
    *   `compassOffset` (Default: `0.0`): Mounting angular offset calibration (set by "Set as North") to align the physical thruster output with magnetic North.
    *   There is deliberately **no separate declination setting**. It existed once, but nothing ever
        applied it to a heading and nothing could set it, and it is redundant anyway: "Set as North"
        is measured against a real bearing, so whatever declination applies where you sail is
        already inside `compassOffset`. Two knobs for one correction only invites applying it twice.
        The `SET_DECLINATION`/`STORE_DECLINATION` commands still exist on the wire so command
        numbering is unchanged, but both ends now ignore them.
*   **Hard & Soft Iron 3D Calibration Matrices (`magHard`, `magSoft`)**:
    *   `magHard[3]` (NVS Keys: `mH00` to `mH02`): 3-axis offset vector used to correct Hard Iron distortions.
    *   `magSoft[3][3]` (NVS Keys: `mS00` to `mS22`): 3x3 scaling matrix used to normalize Soft Iron spatial distortions, generated by the 3D Copilot calibration tool.

### 4. Adaptive Boundary Keep Limits
*   **Hold / Anchor Radius (`holdRad`)**:
    *   `holdRad` (Default: `2.0`): Specifies the circular anchor boundary (in meters) for autonomous station keeping. If the buoy sails inside this radius, thrust is cut to neutral to save battery.

---

## 🛠️ Building & Flashing

RoboSub is built and managed using the **PlatformIO** ecosystem:

Environment **`robo-esp-v3`** (`board = esp32dev`). Libraries: `RoboCompute`, `RoboTone`, PID,
`ESP32Servo`, `FastLED`, SparkFun ICM-20948, Madgwick.

```bash
pio run                                              # build
pio run -t upload                                    # OTA, default 192.168.1.189
pio run -t upload --upload-port sub-fe914828.local   # a different unit
```

`upload_protocol = espota`: the Subs live in sealed hulls and are not on USB, so serial was never
the realistic path. A Sub that has just been reconnected may need a command first to wake it before
it will answer.

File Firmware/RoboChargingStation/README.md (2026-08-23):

# RoboChargingStation (Base Station Firmware)

The `RoboChargingStation` is intended to manage the physical docking and charging infrastructure for the NicE-Buoys.

> ## ⚠️ Status: scaffolding only — no firmware yet
>
> This directory currently contains **only `platformio.ini` and this README**. There is no `src/`,
> no `main.cpp` and nothing to build. Everything below describes the intended design, not working
> behaviour. Treat it as a specification.

## Intended features
- **Communications:** monitor buoy status, location and power levels over LoRa/WiFi.
- **Hardware integration:** drive relays and an MCP23017 I/O expander to engage the docking
  mechanism or charging lines once a buoy is correctly aligned with the dock.
- **State monitoring:** watch the `DOCKING` → `DOCKED` transition and trigger the physical systems
  from it.

## What the project file already declares

`platformio.ini` targets `esp32dev` and pulls in a fairly complete dependency set, which is a
reasonable guide to the intended hardware:

| Library | Suggests |
|---|---|
| `Adafruit_LSM303AGR_Mag`, `Adafruit_LSM303_Accel` | magnetometer + accelerometer (buoy alignment sensing) |
| `Adafruit-MCP23017` | I/O expander for relays |
| `Adafruit_SSD1306`, `Adafruit-GFX` | local OLED status display |
| `arduino-LoRa` | the fleet radio link |
| `TinyGPSPlus` | position |
| `ESP32Servo`, `FastLED` | actuator and status LEDs |
| `ArduinoOTA` | field updates |

Upload is preconfigured as `upload_protocol = espota` to `192.168.4.1` — that is the default ESP32
softAP address, i.e. flashing while connected to the station's **own** access point.

## When it is implemented

It should follow the same conventions as the rest of the fleet — see the
[firmware README](../README.md):

- WiFi priority `NicE_WiFi` → `Robo_WiFi` → its own AP, with `geenanker` as the AP password.
- mDNS via `ArduinoOTA.begin()` only; never a second `MDNS.begin()`.
- Protocol frames on UDP `1001`; a plain-text debug log on UDP `1002` is available for free by
  reusing `udplog.cpp` from `RoboTop`.
- Broadcast beacons must use `ack = INF`. A broadcast asking for an ACK jams a LoRa retry slot for
  five retransmits.

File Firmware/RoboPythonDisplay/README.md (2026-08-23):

# RoboPythonDisplay — Multi-Buoy Desktop Control Dashboard

The **`RoboPythonDisplay`** sub-project is a desktop-based, graphical command-and-control dashboard written in Python utilizing the **Tkinter** user interface toolkit. It provides the pilot with live status updates, spatial mapping, and configuration portals for up to 3 active marine buoys.

---

## 🏗️ System Overview & Communications

RoboPythonDisplay acts as the centralized pilot terminal. It aggregates telemetry from multiple channels and sends downstream mission profiles:

```
┌────────────────────────────────────────────────────────────────────────┐
│                          RoboPythonDisplay                             │
├───────────────────────────────────┬────────────────────────────────────┤
│           UDP Listener            │           Serial Listener          │
├───────────────────────────────────┼────────────────────────────────────┤
│ Receives high-frequency local     │ Connects directly to the USB       │
│ Wi-Fi broadcast telemetry from   │ RoboLora Gateway to receive distant│
│ nearby buoys (Port 1001).         │ long-range RF telemetry packages.  │
└───────────────────────────────────┴────────────────────────────────────┘
```

---

## ⚡ Core Operational Features

### 1. Real-Time Telemetry Visualization
*   **Graphical Windroses & Compasses**: Displays live heading and target direction bearings dynamically.
*   **Thruster Indicators**: Provides vertical bar gauges showing active Port (BB) and Starboard (SB) motor duty cycles (percentage of thrust).
*   **Voltage Tracking Plots**: Monitors battery voltages to track capacity depletion trends in real-time.
*   **GPS Tracking**: Projects live latitude and longitude positions onto an interactive telemetry feed.

### 2. Mission Control Panel
*   **State Machine Overrides**: Allows the pilot to switch the buoy's operational mode at the click of a button between `IDLE`, `MANUAL`, `LOCKED` (GPS Anchor), and `DOCKING` (Waypoint Sailing).
*   **Target Coordinate Injection**: Transmits coordinates and target waypoint distances directly to the buoys' supervisory loops.

### 3. Live In-Field PID Tuning
*   **Sliders Interface**: Displays slider inputs for Proportional, Integral, and Derivative coefficients ($K_p$, $K_i$, $K_d$) for both the Rudder and Speed loops.
*   **OTA Gains Injection**: Transmits the custom coefficients over LoRa. The Sub Unit instantly adopts the new gains without needing physical re-flashing or system restarts.

### 4. Multithreaded GUI Stability
*   **Background Listeners**: Spawns non-blocking daemon threads to process incoming serial COM signals and Wi-Fi UDP sockets asynchronously.
*   **Thread-Safe UI Redrawing**: Implements Tkinter-safe message loops utilizing `master.after()` callbacks, preventing GUI freezes or thread collisions while processing high-volume telemetry.

---

## 🚀 Getting Started

### Prerequisites
Ensure you have Python 3.10+ installed along with necessary dependencies:
```bash
pip install pyserial
```

### Also in this directory
*   **`ota_device_discovery.py`** - scans for OTA-capable nodes on the LAN. Since every node now
    also answers to an mDNS name (`top-<id>.local`, `sub-<id>.local`, `robocyd.local`,
    `lora-<id>.local`), resolving those is usually quicker than a sweep.

### Notes on the telemetry it receives
*   **UDP port 1001** carries the protocol frames. Port **1002** carries a plain-text debug log from
    the Tops and Subs, which is not part of the protocol and can be tailed separately.
*   **Only the Tops transmit on UDP.** The Subs never do - their heading, battery and PID state
    reach you folded into the Top's `TOPDATA`, under the Top's sender ID.
*   **All IDs in a frame are hexadecimal.** The dashboard sends as `99` (`0x99`), the web-authority
    ID; a buoy obeys a broadcast command only from `0x99` or `0x98` (the CYD).

### Running the Dashboard
Connect your **`RoboLora`** USB gateway to an active COM port, navigate to the directory, and launch the application:
```bash
python RoboControl.py
```\n

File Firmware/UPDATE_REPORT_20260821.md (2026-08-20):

# Update report — night of 2026-08-20 / 21

Branch `cyd-setupdata-retry`, commits `9bf2dfab` … `6ebe6b23` (9 commits).
All firmware built and flashed: both Tops (`192.168.1.71`, `192.168.1.78`), both Subs
(one over OTA at `192.168.1.101`, one over USB `COM41`) and the CYD (`COM11`, also on the
network at `192.168.1.235`).

Started from one report — "Active Trim is not stored when set from the web page" — and the
audit that followed pulled in the rest.

---

## What was fixed

### 1. Active Trim did not save — `9bf2dfab`

**Cause.** The Setup page's "Active Trim Enabled" tick box travels in the `SETUPDATA` frame
(field 16, `RoboCode()`). Everything on the way to the Sub was correct, but the Sub's
`SETUPDATA` handler never looked at the field — it stored PIDs, speeds, offset, inversion and
swap and silently dropped the flag. It looked *actively* broken rather than merely inert because
the Sub re-announces its trim state every second over `ADAPTIVE_TRIM`, so the tick box flipped
back on the next `/data` poll. Only the **Toggle Trim** button worked, because that sends
`ADAPTIVE_TRIM`, which the Sub does handle.

**Fix.** The Sub applies and persists the flag via `memCompassTrim()` on `SETUPDATA` SET,
leaving the accumulated trim *value* untouched (it is not in that frame). The Top takes the flag
from both the incoming frame and the Sub's reply so the page updates immediately.

**Verified on hardware** — replaying exactly what UPDATE CONFIG sends, values read back from the
buoy so nothing else changed:

```
start   : enabled=true  trim=-8.774
+2s     : enabled=false trim=-8.774
+4s     : enabled=false trim=-8.774     <- previously reverted within 1 s
+6s     : enabled=false trim=-8.774
restored: enabled=true  trim=-8.774
```

Confirmed on both buoys. Original setting restored afterwards.

### 2. Two more parameters written but never read back — `9bf2dfab`

- `swap_BB_SB` — stored on every save, missing from the boot load.
- `compassOffset` — written to both `magCorr` (double) and the legacy `Delta` (int), but only the
  int was read at boot, throwing away the decimals of an offset the page accepts in 0.1 steps.

Both were later made moot by item 6, which removed them from the Top entirely.

### 3. Mech Corr removed — `9bf2dfab`

Dead system-wide: loaded at compass init and never added to a heading, absent from the wire
format, and unsettable for remote buoys. Had it ever been implemented it would have done exactly
what `compassOffset` already does. **Set as North is not a separate parameter either** — it
computes that same `compassOffset` from the current heading (`RoboSub/src/main.cpp:531`).
Removed from the page, `topwifi.cpp`, both `datastorage` modules, the Sub's compass init and the
shared `RoboStruct`. The orphaned `mechCorr` NVS key is harmless and was left alone.

### 4. Harmonic (Fourier) correction exposed — `bb52a726`

The 8-point table from the GPS calibration is only applied while the Sub's `interp_enabled` is
on, and that switch could previously only be reached from the Sub's own web page — unreachable
from the boat. A buoy could finish a half-hour calibration and keep sailing on an uncorrected
compass with nothing in the UI to say so.

`SETUPDATA` gains **field 20**. It is **tri-state (1 = off, 2 = on)**, not the plain 0/1 the other
flags use: `RoboCode()` compresses an all-zero token to `""`, so a plain 0 could not be told apart
from a field a shorter frame never sent — and `RoboControl.py` still writes `SETUPDATA` frames
that stop at `swap_BB_SB`.

Verified end to end against the Sub's own page, which reports the flag independently:
`Top=true/Sub=1 → toggled → Top=false/Sub=0 → held → restored`.

### 5. Reboot rebooted the buoy five times — `eccf0fc5`, `ff7e85bc`

**Cause.** The Reboot buttons added to the CYD sent `ack = GETACK (3)`, copied from the display's
existing `send_buoy_command()`. `RoboTop/src/loratop.cpp:369` puts any GETACK or SET packet in a
retransmit table with `retry = 5` and resends it about once a second until the target answers —
and the receive path deliberately sends no immediate ACK for a GETACK. A buoy busy rebooting
never answers, so all five retries landed on a freshly booted Top. `retry = 5`, five reboots.

**Fix.** Fire-and-forget actions go out as `INF (6)`, which is not enrolled. `send_buoy_command()`
takes the ack as a defaulted argument so mode changes (LOCK/DOCK/IDLE), where the retry *is*
wanted and the buoy does reply, are untouched. `send_gps_fourier_calibrate()` switched too.
RoboTop additionally ignores a `REBOOT` arriving in its first 15 s of uptime, which breaks the
cycle whatever the sender does.

**Verified:** one command → one reboot (down at 2.9 s, up at 10.5 s, nothing for the next 80 s).

### 6. The Sub owns its own settings — `e3105624`

Thruster inversion and swap describe how the motors are wired to the Sub (`RoboSub/src/esc.cpp:176,181`
is the only code in the system that applies them), and the compass, its offset and both PID loops
are on the Sub as well. All of it already lived in the Sub's NVS. The Top kept a **duplicate** in
its own flash and restored it at boot — two copies of one truth.

That duplication is what made a Sub moved to another hull look like corrupted settings: each Top
went on reporting its stale cache until the new Sub answered, and the two buoys appeared to have
swapped configuration. **Nothing was actually wrong.**

Removed from the Top's flash and boot load, plus the mirrored writes in `handleRfData()` and the
web save: `thrusterInversion`, `thrusterSwap`, `pidRudderParameters`, `pidSpeedParameters`,
`computeParameters`, `CompasOffset` and the legacy int `CompassOffsetCorrection`. The Top keeps a
RAM copy for display and relaying and asks the Sub for `SETUPDATA` at serial link-up, which it
already did. It still owns dock position, dock approach, buoy id and WiFi credentials.

**Verified on a cold boot:** the Top's first HTTP response already carried the Sub's
Kpr/Kps/offset/holdRad/thruster flags — no window in which the Setup dialog could show or save a
blank.

### 7. Dead command path found — `670049ea`

**Desk Calibration never worked from anywhere except the Top's own physical button.** The Sub has
always handled `CALIBRATE_MAGNETIC_COMPASS`, but `handleRfData()` had no case for it, so the web
page's button was silently dropped. Added.

### 8. UI work — `670049ea`, `2a94329b`

- **CYD display**: setup laid out to mirror the web form — six pages, one section heading each
  (PID / SPEED & COMPASS / TRIM & THRUSTERS / DOCKING / CALIBRATION / GPS COMPASS CAL), the
  heading shown as the page title. Slots are now a named table (`SETUP_NAMES`, `enum SetupSlot`)
  with the arithmetic in one `setup_adjust()`, replacing two mirrored if-chains of magic indices —
  the drift that had made the new Harmonic box unselectable. Desk Cal and Reboot added behind the
  two-step the GPS calibration already used.
- **CYD web page** (a separate page from RoboTop's, served at `192.168.1.235`): rebuilt to the
  Top's sections, order and wording. Two things were missing rather than differently arranged:
  **`revBB` had no control at all** — the save echoed back `b.data["revBB"]`, so BB inversion could
  not be changed from that page — and Desk Cal, both GPS Fourier modes and Reboot had no buttons.

### 9. Diagnostics added — `127c4b95`, `6ebe6b23`

`/data` now carries `Uptime`, `ResetReason` (`PANIC` / `WATCHDOG-task` / `BROWNOUT` / `power-on` /
`software`) and the Top's own `TopVolt` / `TopCurr` / `TopPerc`.

---

## The reported crash on 192.168.1.78 — not reproduced

| Test | Result |
|---|---|
| 70 s at 0.4 s polling, 3 min at 1.5 s | no outage, `rev` never reset, `SubOk` true throughout |
| `index.html` ×5, `/data` ×40 rapid, `SETUPDATA` GET, full `SETUPDATA` SET | alive after each |
| LOCK ×3 (45 s, 22 s, 35 s) | `Uptime` climbed straight through all three |
| Rail under full thruster load | 15.28 → 15.26 V; Sub 24.06 → 24.00 V — no sag |

`ResetReason` never left `software`, which is what an OTA restart looks like — and `.78` was
flashed eight times during the session. The most likely explanation is those uploads. Now
instrumented: a real fault will read `PANIC`, `WATCHDOG-task` or `BROWNOUT`.

The bench LOCK trace showed the heading frozen at 79° under full pivot thrust. Per the last water
test that is a bench artefact — the buoy could not physically turn.

---

## Open items

1. **Compass calibration** — the actual blocker per the last water test. The GPS Fourier run is
   now reachable from both UIs, and the Harmonic Correction switch decides whether the resulting
   table is applied. Current state: `b7a5b578` harmonic ON, `b7a5099c` harmonic OFF.
2. **Top battery divider.** Firmware is already byte-identical to the Sub's (same GPIO35, same
   `21.97/1.630`, no attenuation difference in either project), so the discrepancy is a fitted
   component. Top reads 15.27 V against the Sub's 24.06 V on `.78`, and 15.68 vs 24.51 on `.71` —
   agreeing to 0.8%, so a fixed scaling error. If both boards share a pack the constant wants to be
   about **21.16** instead of 13.4785; a 10 kΩ / 500 Ω divider gives exactly 21.0, so the likely
   story is a 10 k fitted on the Top where the Sub has 6.2 k. **Not applied** — deriving it from
   another board's reading assumes a shared pack. Needs a meter. Nothing on the Top acts on this
   value (`main.cpp:1111` only stores it), so it is cosmetic.
3. **±180° wrap chatter.** With the target near-astern the heading error sits on the wrap and the
   command flips full-scale between `BB=-75/SB=+63` and `BB=+75/SB=-75`. Afloat the buoy turns and
   it resolves, so not urgent, but it is a real rough edge in the rudder PID.
4. **`RoboLora/data/index.html`** is a 92 % copy of the CYD's *old* page — same outdated Setup
   form, presumably the same missing `revBB`. Untouched.
5. **`RoboControl.py` writes short `SETUPDATA` SET frames** (stops at `swap_BB_SB`). Fields beyond
   that keep whatever the receiving struct already holds. The count-based guards in `RoboDecode()`
   limit the damage and the new harmonic field is tri-state for exactly this reason, but
   `compass_trim_enabled` and the three dock fields remain exposed.
6. **The Sub disables the ESP32 brownout detector** (`RoboSub/src/main.cpp:153`), the Top does not.
   So a supply dip resets the Top while the Sub carries on. Copying the Sub's line would mask real
   power problems and risks running flash out of spec — worth a deliberate decision rather than
   matching by default.
7. **Intermittent ICM-20948 on one Sub.** One boot logged `ICM-20948: CRITICAL ERROR - Sensor not
   found on I2C bus!` and reported heading 0.00; the next boot found it and read a real heading.
   Flaky power-up or I2C, worth watching.
8. **Unverified suspicions**, noticed while reading and never chased:
   - `handleRfData()` `case ADAPTIVE_TRIM` writes `RfOut->compass_trim*` with no sender check.
   - `case SUBDATA` adopts another node's heading and battery as its own when `IDs == 0`.
   - `is_local` in `case SETUPDATA` is true whenever `from_udp` is true.
   None of these was shown to misbehave; they are listed as places to look, not as findings.

## Hardware notes

- The two Subs were physically swapped between hulls during the session. Since the tuning lives in
  the Sub's NVS, PIDs, compass offset and thruster flags travelled with them — correct behaviour.
- Tops keep stable addresses (`.71` = `f8:b3:b7:a5:09:9c`, `.78` = `f8:b3:b7:a5:b5:78`). Subs move,
  so never assume the pairing: verify by matching the Sub's heading against each Top's `MagDir`.
- ArduinoOTA listens on **UDP** 3232 — scanning TCP 3232 finds nothing. Probe TCP 80 instead.
- A RoboTop change also needs `-t uploadfs`; the CYD serves its own page and needs its own
  `uploadfs`. Its `platformio.ini` says `COM15`, but it enumerated as `COM11`.

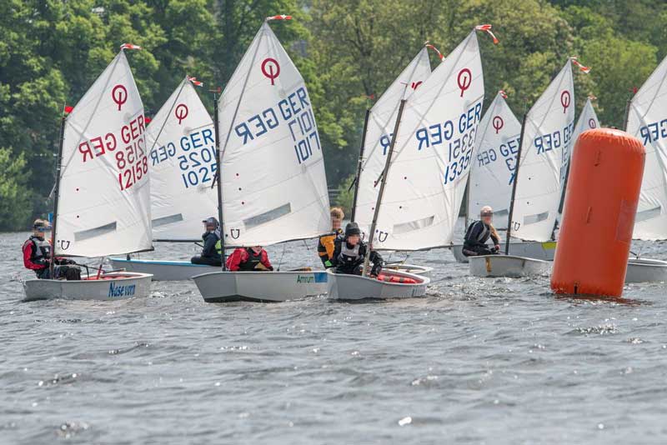
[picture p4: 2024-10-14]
Doc/2023_juengstenfestival_12.jpg

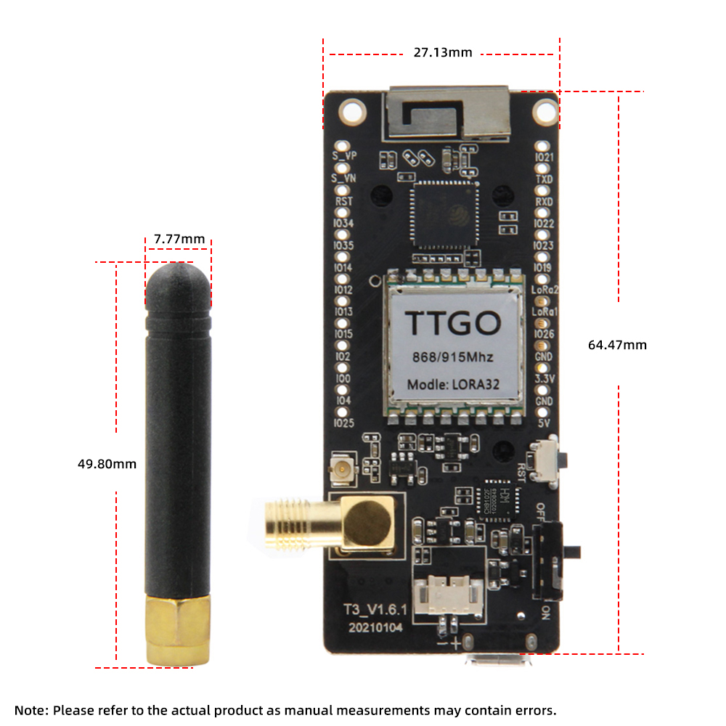
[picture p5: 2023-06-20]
Doc/lillygo_T3_V1.6.1_dementions.jpg

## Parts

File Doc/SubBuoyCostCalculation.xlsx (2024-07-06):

NicE Bobobuoy
TOP
1 | GPS | Neo8 | €15.00 | €15.00
1 | PCB | NicE RobobuoyTopV1.0 | €35.00 | €35.00
1 | Casing | Fillament/Oring | €28.00 | €28.00
1 | antenne | 433MHz | €5.00 | €5.00
1 | accu | LiPo 1S | €3.80 | €3.80
1 | Div |  | €10.00 | €10.00
 |  |  |  | €96.80
SUB
2 | Trusters | TOOPRE | €22.50 | €45.00
2 | Accu | S6 DXF LIPO 8500Mah | €73.40 | €146.80
1 | Connectors | M16 pcb 10p | €11.70 | €11.70
2 | ESC | 40A S6 | €16.70 | €33.40
1 | PCB | NicE BobobuoySubV1.0 | €50.00 | €50.00
1 | Casing | Fillament/Oring | €15.00 | €15.00
1 | Div |  | €20.00 | €20.00
 |  |  |  | €321.90
Total buoy |  |  |  | €418.70
Charger
3 | Charger | Toolkitrc C6 50W Lipo Lihv | €30.00 | €90.00
1 | Casing |  | €100.00 | €100.00
1 | wiring |  | €50.00 | €50.00
1 | lora | Lora module 433Mhz | €8.00 | €8.00
1 | Wifi | ESP32 | €5.00 | €5.00
3 | Connectors | Div | €20.00 | €60.00
 |  |  |  | €313.00
Total system |  |  |  | €1569.10

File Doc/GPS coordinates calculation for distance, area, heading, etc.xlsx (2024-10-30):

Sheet: end & midpoint
Input data: Start point, Heading, Distance
 | START POINT |  | INITIAL HEADING | DISTANCE (km) | EARTH RADIUS (km)
 | Latitude | Longitude
 | 59.800278 | 30.262500 | 0.147 | 6570.68 | 6378.14 | http://en.wikipedia.org/wiki/Earth_radius
 | MID POINT
 | Latitude | Longitude | HEADING
 | 89.309101 | 36.265637 | 6.130
 | END POINT |  | FINAL HEADING
 | Latitude | Longitude
 | 61.174170 | -149.998330 | 179.844
GUIDE |  |  |  |  |  | PETUNJUK
Latitude = South or North |  |  |  |  |  | Lintang = Selatan atau Utara
Longitude = East or West |  |  |  |  |  | Bujur = Timur atau Barat
North and East coordinates have positive number (+) |  |  |  |  |  | Koordinat Utara dan Timur mempunyai angka positif (+)
South and West coordinates have negative number (-) |  |  |  |  |  | Koordinat Selatan dan Barat mempunyai angka negatif (-)
Input in yellow cells only |  |  |  |  |  | Input hanya di sel kuning
Blue cells contain formulae |  |  |  |  |  | Sel biru berisi formula
Initial heading is direction when leaving start point |  |  |  |  |  | Initial heading adalah arah ketika meninggalkan titik start
Final heading is direction when arriving at end / destination point |  |  |  |  |  | Final heading adalah arah saat tiba di titik akhir atau tujuan
Mid point heading is direction when arriving at mid point to end point |  |  |  |  |  | Mid point heading adalah arah saat tiba di titik tengah menuju tujuan
Mid point is coordinates in halfway distance |  |  |  |  |  | Mid point adalah koordinat dipertengahan
Earth radius can be changed for better accuracy to suit different location |  |  |  |  |  | Radius bumi dapat dirubah agar lebih akurat sesuai perbedaan lokasi
Change km to mile by writing earth radius in mile |  |  |  |  |  | Rubah km ke mil dengan menulis radius bumi dalam mil
More detail in article: |  |  |  |  |  | Lebih detail di artikel:
http://maruzar.blogspot.com/2013/04/find-gps-destination-by-start-point.html |  |  |  |  |  | http://maruzar.blogspot.com/2013/03/kalkulasi-koordinat-gps-berdasar-data.html

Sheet: heading & distance
Heading & Distance calculation by 2 GPS Coordinates
 | Latitude | Longitude | Heading
Start | 59.800278 | 30.262500 | 0.147 | Initial
End | 61.174170 | -149.998330 | 179.844 | Final
Midpoint | 89.309101 | 36.265637 | 6.130 | Mid
Distance (km) | 6570.679 | Earth radius | 6378.14 | http://en.wikipedia.org/wiki/Earth_radius
GUIDE |  |  |  |  | PETUNJUK
Latitude = South or North |  |  |  |  | Lintang = Selatan atau Utara
Longitude = East or West |  |  |  |  | Bujur = Timur atau Barat
North and East coordinates have positive number (+) |  |  |  |  | Koordinat Utara dan Timur mempunyai angka positif (+)
South and West coordinates have negative number (-) |  |  |  |  | Koordinat Selatan dan Barat mempunyai angka negatif (-)
Input in yellow cells only |  |  |  |  | Input hanya di sel kuning
Blue cells contain formulae |  |  |  |  | Sel biru berisi formula
Initial heading is direction when leaving start point |  |  |  |  | Initial heading adalah arah ketika meninggalkan titik start
Final heading is direction when arriving at end / destination point |  |  |  |  | Final heading adalah arah saat tiba di titik akhir atau tujuan
Mid point heading is direction when arriving at mid point to end point |  |  |  |  | Mid point heading adalah arah saat tiba di titik tengah menuju tujuan
Mid point is coordinates in halfway distance |  |  |  |  | Mid point adalah koordinat dipertengahan perjalanan
Earth radius can be changed for better accuracy to suit different location |  |  |  |  | Radius bumi dapat dirubah agar lebih akurat sesuai perbedaan lokasi
Change km to mile by writing earth radius in mile |  |  |  |  | Rubah km ke mil dengan menulis radius bumi dalam mil
More detail in article: |  |  |  |  | Lebih detail di artikel:
http://maruzar.blogspot.com/2011/10/calculate-straight-distance-between-two.html |  |  |  |  | http://maruzar.blogspot.com/2011/10/jika-anda-perlu-menghitung-jarak-garis.html
http://maruzar.blogspot.com/2012/12/calculating-heading-or-bearing-angleof.html |  |  |  |  | http://maruzar.blogspot.com/2012/11/menghitung-sudut-heading-atau-bearing.html

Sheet: area & perimeter
Land Lot Area and Perimeter Calculation
 |  |  | Earth
 |  |  | http://en.wikipedia.org/wiki/Earth_radius
 |  |  | Radius | 6378137 | meters
 |  |  | Diameter | 12756274 | meters
 |  |  | Circumference | 40091146.86 | meters
 | Latitude | Longitude | Y | X | Area | Perimeter
 | -6.177570 | 106.825820 | 0 | 0
 | -6.176810 | 106.824920 | 84.63686559 | -99.64553568 | 0.0 | 130.7
 | -6.173840 | 106.824970 | 415.3888272 | -94.11020084 | 16713.2 | 330.8
 | -6.173130 | 106.825700 | 494.4574779 | -13.28616382 | 20507.3 | 113.1
 | -6.173180 | 106.828800 | 488.8892631 | 329.9397038 | 84818.3 | 343.3
 | -6.173900 | 106.829430 | 408.7069693 | 399.6915136 | 30278.1 | 106.3
 | -6.176730 | 106.829390 | 93.54600933 | 395.2606847 | 62078.1 | 315.2
 | -6.177660 | 106.828450 | -10.02278671 | 291.1859308 | 15600.4 | 146.8
 | -6.177570 | 106.825820 | 0 | 0 | 0.0 | 291.4
 |  |  | 0 | 0 | 0.0 | 0.0
 |  |  | 0 | 0 | 0.0 | 0.0
 |  |  | 0 | 0 | 0.0 | 0.0
 |  |  | 0 | 0 | 0.0 | 0.0
 |  |  | 0 | 0 | 0.0 | 0.0
 |  |  | 0 | 0 | 0.0 | 0.0
 |  |  | 0 | 0 | 0.0 | 0.0
 |  |  | 0 | 0 | 0.0 | 0.0
 |  |  | 0 | 0 | 0.0 | 0.0
 |  |  | 0 | 0 | 0.0 | 0.0
 |  |  | 0 | 0 | 0.0 | 0.0
 |  |  | Total |  | 229995.5 | 1777.5
 |  |  |  |  | m2 | m
GUIDE |  |  |  |  |  |  | PETUNJUK
Longitude = East or West |  |  |  |  |  |  | Bujur = Timur atau Barat
Latitude = South or North |  |  |  |  |  |  | Lintang = Selatan atau Utara
North and East coordinates have positive number (+) |  |  |  |  |  |  | Koordinat Utara dan Timur mempunyai angka positif (+)
South and West coordinates have negative number (-) |  |  |  |  |  |  | Koordinat Selatan dan Barat mempunyai angka negatif (-)
Input data in yellow cells only |  |  |  |  |  |  | Input data hanya pada sel kuning
Always input from top cells |  |  |  |  |  |  | Selalu input dari sel paling atas
No empty row in the middle |  |  |  |  |  |  | Tidak ada baris kosong ditengah data
List vertices in clockwise order |  |  |  |  |  |  | Titik sudut diurut berdasarkan putaran jam
Start at lower left vertex (starting point) |  |  |  |  |  |  | Mulai dari sudut bawah kiri (titik start)
End data with the same vertex (starting point), to make closed polygon |  |  |  |  |  |  | Akhiri data dengan sudut bawah kiri (titik start), agar poligon menjadi tertutup
Make sure longitude and latitude are written in correct collumn |  |  |  |  |  |  | Pastikan bujur dan lintang ditulis pada kolom yang benar
Google maps uses latitude and longitude data sequence, not vice versa |  |  |  |  |  |  | Google maps menggunakan urutan data lintang dan bujur, bukan sebaliknya
Earth circumference can be adjusted |  |  |  |  |  |  | Keliling bumi dapat disesuaikan
Change meter to feet by writing earth radius in feet |  |  |  |  |  |  | Rubah meter ke feet dengan menulis radius bumi dalam feet
http://maruzar.blogspot.com/2012/03/calculating-land-lot-area-with-gps.html |  |  |  |  |  |  | http://maruzar.blogspot.com/2012/03/menghitung-luas-tanah-dengan-koordinat.html

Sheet: conversion
Coordinates conversion | Global Positioning System
 |  |  |  |  |  | GUIDE
Convert latitude and longitude in sexagesimal (degrees minutes seconds) to decimal. |  |  |  |  |  | Latitude = South or North
Konversi lintang dan bujur dari sexagesimal (derajat menit detik) menjadi desimal |  |  |  |  |  | Longitude = East or West
 |  |  |  |  |  | Blue cells contain formulae
 |  | Input Sexagesimal coordinate |  |  | Output
 |  | Degree | Minute | Second | in decimal | North and East coordinates have positive number (+)
 | latitude | -22 | -54 | -12 | -22.903333 | South and West coordinates have negative number (-)
 | longitude | -43 | -12 | -34 | -43.209444 | Negative value for South and West must be written on all columns (Degree, Minute, Second)
 |  |  |  |  |  |  | like Rio de Janeiro Sexagesimal coordinates
Convert latitude and longitude in decimal to sexagesimal (degrees minutes seconds).
Konversi lintang dan bujur dari desimal menjadi sexagesimal (derajat menit detik) |  |  |  |  |  | PETUNJUK
 |  |  |  |  |  | Lintang = Selatan atau Utara
 |  | Input | Output Sexagesimal coordinate |  |  | Bujur = Timur atau Barat
 |  | in decimal | Degree | Minute | Second | Sel biru berisi formula
 | latitude | -22.903333 | -22 | -54 | -12
 | longitude | -43.209444 | -43 | -12 | -34 | Koordinat Utara dan Timur mempunyai angka positif (+)
 |  |  |  |  |  | Koordinat Selatan dan Barat mempunyai angka negatif (-)
 |  | examples of Sexagesimal |  |  |  | Nilai negatif dari Selatan dan Barat harus ditulis di semua kolom (Degree, Minute, Second)
 |  | Jakarta |  | 6°10'31"S | 106°49'37"E |  | seperti Rio de Janeiroo Sexagesimal koordinat
 |  | Bangkok |  | 13°45′8″N | 100°29′38″E
 |  | Singapore |  | 1°17′N | 103°50′E
 |  | Rio de Janeiro |  | 22°54′12″S | 43°12′34″W

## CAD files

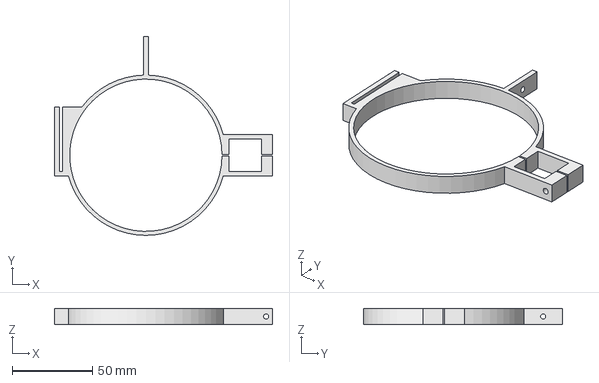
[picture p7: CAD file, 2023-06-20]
3D/BottleHolder2_0-BottleholderBottom2_001.step
136.0 x 124.0 x 10.0 mm

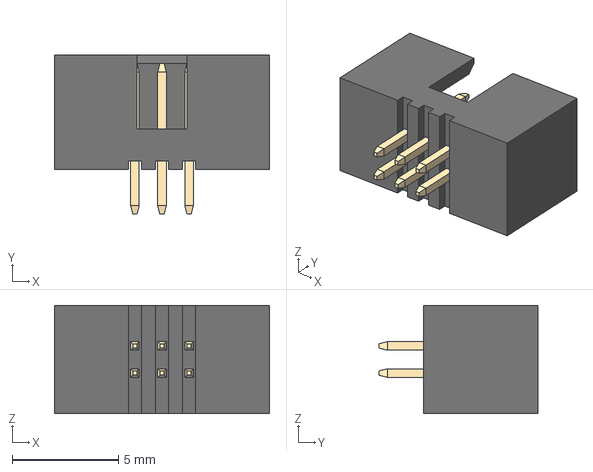
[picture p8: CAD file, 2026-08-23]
Datasheets/IDC_1.27mm_2x3.step
10.1 x 7.50 x 5.10 mm

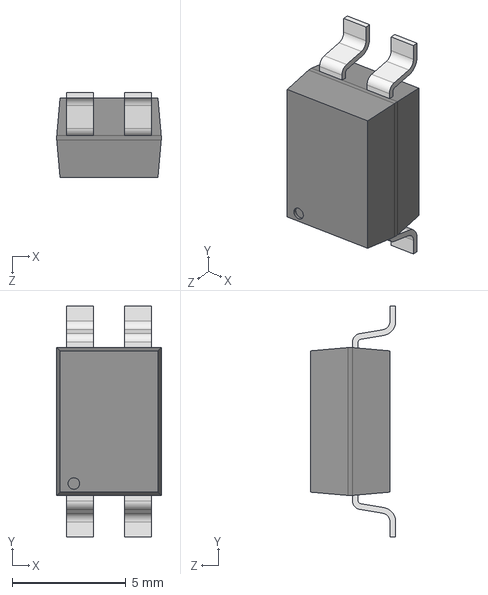
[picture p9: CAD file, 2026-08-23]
Datasheets/User Library-4-SMD/User Library-4-SMD.STEP
4.60 x 10.2 x 3.76 mm

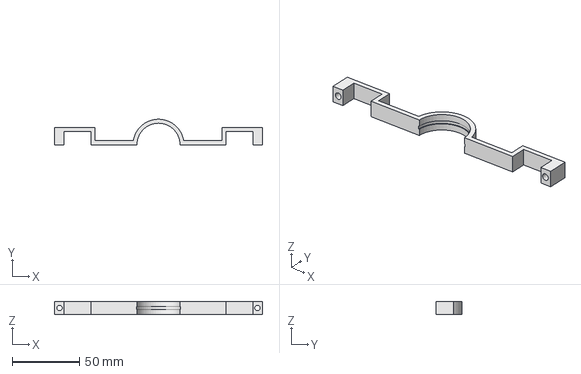
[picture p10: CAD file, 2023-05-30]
Doc/PedFlesHouder.FCStd
154.5 x 19.0 x 10.0 mm

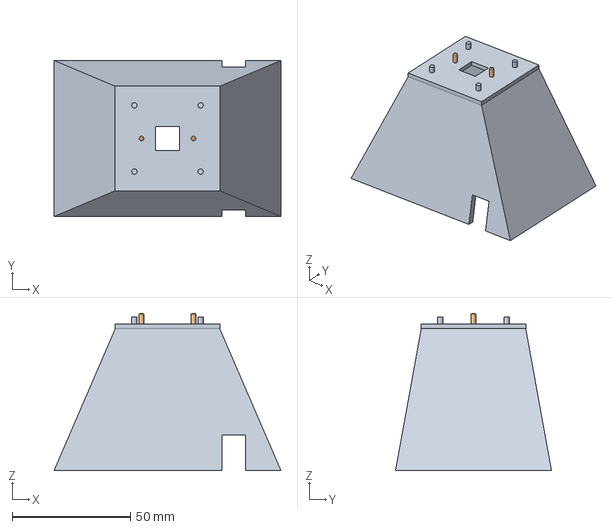
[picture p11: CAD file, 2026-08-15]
Firmware/RoboCYD/Doc/CameraCasingFIT0729Outside.step
96.0 x 66.0 x 66.5 mm

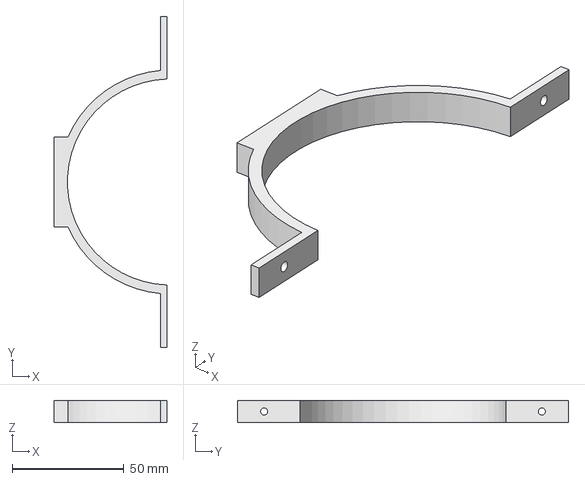
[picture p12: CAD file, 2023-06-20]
3D/BottleHolde2_0-BottleholderBigMiddel2_0.step
50.5 x 148.0 x 10.0 mm

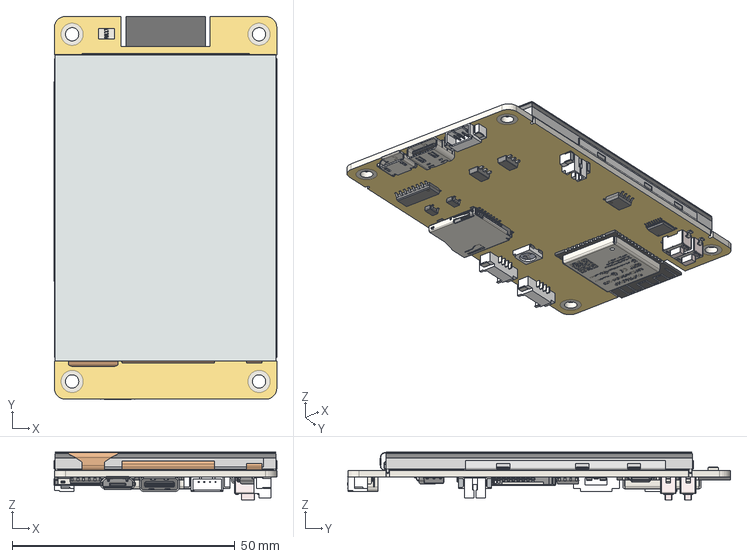
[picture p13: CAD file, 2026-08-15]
Firmware/RoboCYD/Doc/ESP32_2432S028 (CYD).step
50.1 x 86.1 x 10.7 mm

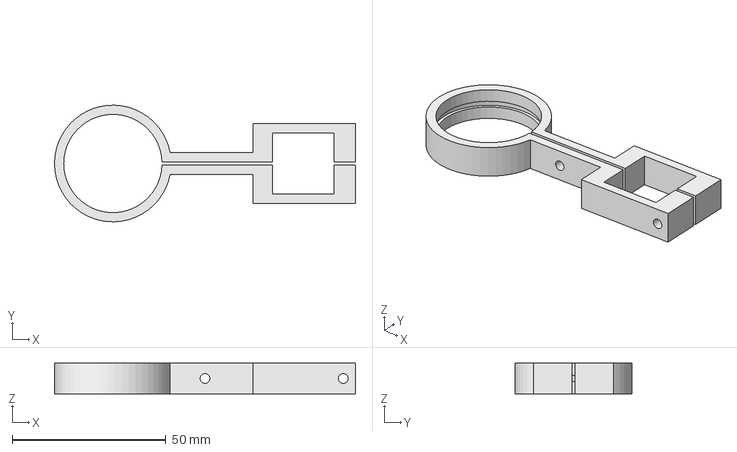
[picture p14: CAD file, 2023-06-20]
3D/BottleHolder2_0-BottleholderFrontBig2_001.step
98.0 x 38.0 x 10.0 mm

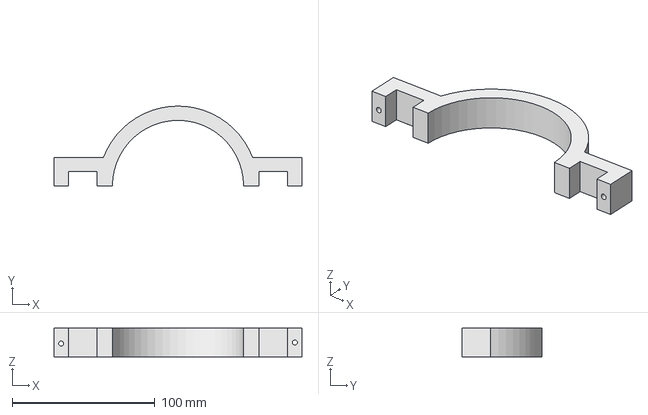
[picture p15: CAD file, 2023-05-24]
3D/PadFlesHalsHouder-PedFlesBodyHolder.step
174.0 x 56.0 x 20.0 mm

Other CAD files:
3D/BottleHolder2_0-BottleholderBigMiddel2_0.step
3D/BottleHolde2_0-BottleholderBottom2_001.step
Firmware/RoboCYD/Doc/ESP32_2432S028 (CYD).f3d

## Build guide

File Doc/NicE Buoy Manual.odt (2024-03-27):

NicE Buoy Manual

# Installation

To setup the buoy we have to do two things first.

1 Calibrating the compass

2 Calibrating the heading

# Calibrate comas

Press and hold the button when turning the Buoy power on.

Wait for 5 seconds. The buoy will beeb.

The red power light will flash.

Turn the buoy around in al direction and all axes for more than one minute. When the led is green and a beep has sounded the buoy compass calibration is done.

# Calibrate heading

Mark the place where the buoy is laying.

Turn the buoy on and wait until the green powered is on continues on.

Push the button for 5 seconds.. A beep will be generated an the button will flash.

Put the buoy more than 50 meters form the marked spot.

Point the buoy front to the marked place

Push the button again for more than 5 seconds.

The heading calibration is done.

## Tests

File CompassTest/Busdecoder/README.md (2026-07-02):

# Serial Plotter Instructions

I have created a Python script that can monitor and plot data from a serial port in real-time.

## Prerequisites
Ensure you have the required Python libraries installed:
```cmd
pip install pyserial matplotlib
```

## Step 1: Update Firmware
Based on the reference code in `PIOCompass`, the device does not continuously output data over the Serial port. You need to update your ESP32 firmware (`main.cpp`) to output comma-separated values. 

Add the following line inside the `loop()` function (e.g., right before `strip.show();`):
```cpp
Serial.printf("%.2f,%.2f,%.2f,%.2f\n", g_data.magX, g_data.magY, g_data.magZ, g_data.heading);
```

## Step 2: Find your COM Port
Run the helper script to list available COM ports on your system:
```cmd
python list_ports.py
```

## Step 3: Run the Plotter
Run the plotter script with your COM port:
```cmd
python serial_plotter.py --port COM3
```
*(Replace `COM3` with your actual COM port).*

The script will automatically detect the number of comma-separated values coming over the serial port and plot each as a separate line.

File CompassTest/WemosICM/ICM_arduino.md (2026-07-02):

# Heltec Wireless Tracker & LSM303AGR Compass Project Specification

## 1. Project Overview
This specification outlines the architectural and functional requirements for an Arduino-based firmware application targeting the **Heltec Wireless Tracker** (ESP32-S3 with onboard 0.96" TFT display, GPS, and LoRa). The application integrates an **LSM303AGR** sensor (accelerometer and magnetometer) to function as a tilt-compensated compass. It hosts a dynamic web portal from internal SPIFFS storage, streams real-time $100\text{Hz}$ telemetry over WebSockets, and supports Over-the-Air (OTA) firmware updates.

---

## 2. Hardware Configuration & Pinout

### 2.1. Power and General Control
- **LED Pin:** `18` (Onboard LED indicator, flashes as a loop heartbeat)
- **VEXT Power Enable:** `3` (Set `HIGH` to enable power rails for the TFT display, GNSS, and peripheral devices)

### 2.2. Display Configuration (ST7735 Mini 160x80)
The built-in display is a **0.96-inch 160x80 IPS TFT screen** driven by the `Adafruit_ST7735` library using **Hardware SPI** (running at up to 40MHz for flicker-free rendering) configured in landscape mode.
- **Backlight Pin (BL_PIN):** `21` (Set `HIGH` to enable display backlight)

| Signal Name | Pin Number | Description |
| :--- | :--- | :--- |
| `TFT_CS` | `38` | Chip Select |
| `TFT_RST` | `39` | Reset |
| `TFT_DC` | `40` | Data / Command Selection |
| `TFT_SCLK` | `41` | SPI Clock (Hardware SPI SCLK) |
| `TFT_MOSI` | `42` | SPI MOSI (Hardware SPI MOSI) |

**Instantiation & Initialization Example:**
```cpp
#include <SPI.h>
#include <Adafruit_ST7735.h>

// Initialize using the 3-argument Hardware SPI constructor
Adafruit_ST7735 tft = Adafruit_ST7735(TFT_CS, TFT_DC, TFT_RST);

void setupDisplay() {
    pinMode(VEXT_PIN, OUTPUT);
    digitalWrite(VEXT_PIN, HIGH); // Enable display power
    delay(100);
    pinMode(BL_PIN, OUTPUT);
    digitalWrite(BL_PIN, HIGH);   // Turn on backlight
    
    // Assign Hardware SPI pins on the ESP32-S3 and initialize
    SPI.begin(TFT_SCLK, -1, TFT_MOSI, TFT_CS);
    tft.initR(INITR_MINI160x80); // Initialize for 160x80 screen size
    tft.setRotation(1);          // Set rotation to landscape
}
```

### 2.3. ICM-20948 I2C Sensor Pins
The LSM303AGR sensor is connected via the standard ESP32 I2C bus configured for Fast-Mode ($400\text{kHz}$).

| Signal Name | Pin Number | Description |
| :--- | :--- | :--- |
| `I2C_SDA` | `4` | I2C Data Line |
| `I2C_SCL` | `5` | I2C Clock Line |

---

## 3. Core Functional Requirements

### 3.1. Network & OTA Updates
* **Wi-Fi Connectivity:**
  * **SSID:** `NicE_WiFi`
  * **Password:** `!Ni1001100110`
* **Over-the-Air (OTA) Updates:**
  * Implement standard `ArduinoOTA` wireless update services.
  * Provide visual status progress bars on the ST7735 display during OTA transfers.

### 3.2. Compass & Sensor Fusion (ICM-20948)
* **Hardware Output Data Rate (ODR) Configuration:**
  * Explicitly reconfigure the physical sensor registers on startup to eliminate hardware undersampling and capture high-speed motion:
    * Set the **ICM-20948 Magnetometer** ODR to **100Hz** using `setDataRate(LIS2MDL_RATE_100_HZ)`.
    * Set the **ICM-20948 Accelerometer** ODR to **200Hz** by writing `0x67` directly to register `CTRL_REG1_A` (address `0x20`) on I2C address `0x19`.
* **Physical Coordinate Axes Alignment:**
  * Transform raw magnetometer axes to align with the accelerometer's coordinate frame prior to performing tilt compensation:
    * $X_{aligned} = -Y_{raw\_lsm}$
    * $Y_{aligned} = X_{raw\_lsm}$
    * $Z_{aligned} = Z_{raw\_lsm}$
* **Tilt-Compensated Heading Calculation:**
  * Calculate Roll ($\phi$) and Pitch ($\theta$) from the accelerometer:
    * $\text{Roll} = \arctan2(Ay, Az)$
    * $\text{Pitch} = \arctan2(-Ax, \sqrt{Ay^2 + Az^2})$
  * Rotate the aligned magnetic vector into the horizontal plane:
    * $X_h = M_{x\_aligned} \cos(\text{Pitch}) + M_{y\_aligned} \sin(\text{Roll})\sin(\text{Pitch}) + M_{z\_aligned} \cos(\text{Roll})\sin(\text{Pitch})$
    * $Y_h = M_{y\_aligned} \cos(\text{Roll}) - M_{z\_aligned} \sin(\text{Roll})$
  * Compute Heading = $\arctan2(Y_h, X_h) \times \frac{180}{\pi}$ (with $0^\circ$ to $360^\circ$ normalization, checking for standard positive rotation).

### 3.3. Calibration & Non-Volatile Storage (NVM)
* **Calibration Algorithms:**
  * **Hard-Iron Calibration:** Corrects for constant magnetic offsets ($V_{hx}, V_{hy}, V_{hz}$).
  * **Soft-Iron Calibration:** Corrects for magnetic field deformation and axis scaling distortions ($S_x, S_y, S_z$).
* **Non-Volatile Memory (NVM):**
  * Load and persist hard-iron offsets and soft-iron scale factors dynamically from NVM (`Preferences` namespace `"calibration"`) to protect settings across reboots.

### 3.4. Dynamic Web Server & Multi-Core Architecture (SPIFFS Hosted)
To guarantee a solid, jitter-free $100\text{Hz}$ telemetry stream, the firmware must utilize the ESP32's dual-core architecture:
1. **Core 0 Sensor Thread (FreeRTOS Task):**
   * A dedicated, high-priority FreeRTOS task pinned to **Core 0** that performs jitter-free $100\text{Hz}$ (every 10ms) I2C hardware polling, axes alignment, and tilt compensation.
   * Telemetry is written to a shared memory structure protected by a hardware spinlock (`portENTER_CRITICAL` / `portEXIT_CRITICAL`).
2. **Core 1 Application Thread (Main Loop):**
   * Dedicated to network requests, `ArduinoOTA`, Web Server, and TFT screen drawing.
   * Extracts telemetry safely from Core 0 and dispatches it immediately to WebSocket clients.
3. **Active Network Congestion Control:**
   * To prevent client disconnection loops, the WebSockets dispatcher must implement an active **frame-skipping queue check**. A telemetry packet is only sent to a client if its pending queue length is empty or has space: `client.queueLen() < 2`. If Congested, that specific frame is skipped.
4. **Dynamic Screen Throttling:**
   * Drawing text on local screens takes time. To maximize network throughput during active calibration, the loop must dynamically throttle the ST7735 display's refresh interval from **$300\text{ms}$ down to $2000\text{ms}$** when the `start_cal` signal is active.

---

## 4. Frontend Specifications (HTML/CSS/JS in SPIFFS)

Static assets are stored on internal SPIFFS, loaded once, and cached.

### 4.1. Comparative SVG Windroses
The interface displays two side-by-side, high-contrast inline SVG compass windroses:
- **Windrose A:** Displays tilt-compensated heading with **Hard-Iron only** calibration.
- **Windrose B:** Displays tilt-compensated heading with **Hard + Soft-Iron** calibration.
- **Visual styling:** Dark theme circular dials with cardinal labels (N in red, E, S, W in slate), cyan dashed inner rings, and a 3D split-shaded needle (red/slate) with a gold cap.
- **Shortest-Path Rotation:** Needle rotation animated via CSS `transform` using shortest-path angular math to prevent flipping or spinning when crossing the $0^\circ / 360^\circ$ boundary.

### 4.2. Real-Time 3D Orientation Visualizer
- Renders an interactive 3D model representing the physical tracker board rotating inside a wireframe bounding grid.
- **Reference Frame:** A fixed circular ground compass with 'N', 'S', 'E', and 'W' sprite markers is rendered on the floor to provide a spatial frame of reference.
- **Standard Euler Rotations:** Rotations are mapped strictly to standard Yaw-Pitch-Roll (Euler 'YXZ') flight-dynamics coordinates to eliminate mathematical gimbal locks.

### 4.3. Interactive 3D Calibration Portal
- **Real-Time Scatter Plot:** Displays live coordinate points as they are streamed over WebSockets, drawn instantly as 2D projections (X-Y and Y-Z planes) on a dark canvas using fast hardware-accelerated `fillRect()` methods.
- **Mathematical Solver (Client-side JS):** Collects raw points and performs mathematical center offsets and scale normalization to solve for hard-iron and soft-iron parameters.
- **Storage Hook:** Once computed, clicking "Store Calibration" transmits parameters back to the ESP32 over WebSockets to be written to NVM.

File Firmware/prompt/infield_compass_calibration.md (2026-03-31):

# In-Field Autonomous Compass Calibration

## Objective
Implement an autonomous "In-Field Calibration" routine that runs while the buoy is deployed in the water. The user will trigger this procedure from the Python control script. The buoy will perform a sequence of maneuvers (circles of varying radii) to collect comprehensive magnetometer data, calculate hard-iron (and optionally soft-iron) calibration factors, store them in NVS, and return to an idle state.

## 1. User Interface (RoboLog/RoboControl.py)
*   **New Button**: Add an "In-Field Calib" button below or next to the existing "SETUP" button for each buoy.
*   **Confirmation Dialog**: Since this makes the buoy move autonomously, prompt the user: *"Deploying In-Field Calibration will cause the buoy to move in circles for ~60 seconds. Ensure the area is clear. Continue?"*
*   **Command Transmission**: Send a specific command ID (e.g., `CMD = 70`) over UDP and/or LoRa to the target buoy.
*   **Status Feedback**: Update the `Status` label in the GUI to `"CALIBRATING"` while the command is running (the buoy should broadcast its status as 70 during this time).

## 2. Communication Protocol (RoboCompute.h & RoboCompute.cpp)
*   **New Command Constant**: Define `INFIELD_CALIBRATE = 70` in `RoboCompute.h` alongside existing commands like `PIDRUDDER` or `MAXMINPWR`.
*   **Message Routing**: Ensure `RobobuoyTop` correctly routes `CMD 70` to `RobobuoySub` via the serial link.

## 3. Sub Firmware State Machine (RobobuoySub)
*   **Trigger Handling (`main.cpp`)**: When `ser->cmd == INFIELD_CALIBRATE` is received, change the buoy's internal status to `CALIBRATING` and trigger the calibration sequence.
*   **Non-Blocking Sequence (`compass.cpp` or `esc.cpp`)**: Implement a timer-based state machine that prevents the `loop()` from blocking while the buoy moves.
*   **Proposed Smart Maneuver Sequence**:
    *   **Phase 0 - Initialization & Home**: 
        *   **RECORD HOME (P0)**: Log the current GPS coordinates (`Lat0, Lon0`) as the starting point to return to later.
    *   Since the buoy moves slowly, simple fixed timers (like 15 seconds) are insufficient. The calibration routine should ideally run for **at least 2-3 minutes total**.
    *   **Phase 1 (~60s) - Wide Right Turn**: Set `bb = 20%`, `sb = 5%`.
    *   **Phase 2 (~60s) - Wide Left Turn**: Set `bb = 5%`, `sb = 20%`.
    *   **Phase 3 (~30s) - Pivot Right**: Set `bb = 25%`, `sb = -25%`.
    *   **Alternative (Smart Rotation Detection)**: Instead of rigid timers, integrate a gyro/compass check to count complete 360° rotations. For example, instruct the buoy to turn right until it has completed two full rotations, then turn left for two full rotations. This ensures comprehensive data collection regardless of wind/current resistance.
    *   *Note: Thrust values should scale with `rud->maxSpeed` to ensure they are safe but effective.*
*   **Data Collection**:
    *   Continuously sample the raw magnetometer values (`event.magnetic.x`, `y`, `z`).
    *   Track the absolute minimums and maximums (`min_mag[3]`, `max_mag[3]`).
    *   *(Optional Enhancement)*: Stream this raw data back to the Python script (using the `RAWCOMPASSDATA` command) so the user can see a live scatter plot of the calibration circle filling in.

## 4. Calculation & Storage
*   **End of Sequence**: Once the time expires (or rotations are complete), stop the thrusters (`bb = 0`, `sb = 0`).
*   **Hard-Iron Calculation**: 
    ```cpp
    compassCalc.magHard[0] = (max_mag[0] + min_mag[0]) / 2.0f;
    compassCalc.magHard[1] = (max_mag[1] + min_mag[1]) / 2.0f;
    compassCalc.magHard[2] = (max_mag[2] + min_mag[2]) / 2.0f;
    ```
*   **Soft-Iron Calculation (Simple Approach)**: Reset the soft-iron matrix to the identity matrix (`1.0` on the diagonal, `0.0` elsewhere) unless a more advanced least-squares fitting algorithm is implemented.
*   **Storage**: Call the existing `hardIron(&compassCalc, SET)` and `softIron(&compassCalc, SET)` functions to persist the data to the ESP32 Preferences (NVS).
*   **Feedback**: Play a success tone on the buzzer.
*   **Return Home**: 
    *   After the calibration is successfully stored and active, set the target coordinates to `Lat0, Lon0` (the Home point recorded in Phase 0).
    *   Engage standard GPS/Compass autonomous navigation logic.
    *   Once the buoy is back within range (e.g., 2m of P0), stop thrusters and return the status to `IDLE` (7).

## 5. Safety & Edge Cases
*   **Abort Mechanism**: If the user sends an `IDLE` (8) or `LOCK` (12) command while the calibration is running, the sequence must immediately abort, stop the motors, and discard the collected data.
*   **Communication Loss**: If the buoy loses communication with the controller, it should ideally continue and finish the 60-second calibration, then stop. However, if the watchdog timer is strictly enforced, ensure the calibration routine feeds the watchdog or handles timeouts gracefully.
*   **Sensible Limits**: Reject calibration if the `max - min` range is suspiciously small (e.g., `< 10 µT`), which might indicate a broken sensor rather than a valid calibration circle.

## 6. Implementation Steps for the Developer (LLM)
1. Add the `INFIELD_CALIBRATE` command to `RoboDependency/RoboCompute`.
2. Update `RobobuoyTop/src/main.cpp` to forward the command.
3. In `RobobuoySub/src/compass.cpp`, write the `InFieldCalibrationTask` or state machine.
4. Update `RoboLog/RoboControl.py` with the UI button and confirmation logic.

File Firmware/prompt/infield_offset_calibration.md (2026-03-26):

# In-Field Autonomous Offset Calibration (GPS vs. Compass)

## Objective
Implement an autonomous "In-Field Offset Calibration" routine to align the magnetic compass with the true GPS course. The buoy will sail a straight line using only its compass for navigation, then compare the actual path taken (measured by GPS) to the intended magnetic heading. The resulting angular difference is the `compassOffset`.

## 1. User Interface (RoboLog/RoboControl.py)
*   **New Button**: Add an "In-Field Offset" button next to the "In-Field Calib" button.
*   **Confirmation Dialog**: Prompt the user: *"Deploying In-Field Offset Calibration will cause the buoy to sail South for ~2 minutes. Ensure you have enough open water to the South. Continue?"*
*   **Command Transmission**: Send a specific command ID (e.g., `CMD = 71`) over UDP and/or LoRa.
*   **Status Feedback**: The buoy should broadcast status `71` while calibrating.

## 2. Communication Protocol
*   **New Command Constant**: Define `INFIELD_OFFSET_CALIBRATE = 71` in `RoboCompute.h`.
*   **Routing**: Ensure `RobobuoyTop` forwards `CMD 71` to `RobobuoySub`.

## 3. Sub Firmware State Machine (RobobuoySub)
*   **Trigger Handling**: When `CMD 71` is received, set buoy status to `71` and start the sequence.
*   **Calibration Sequence (Total ~300+ seconds)**:
    *   **Phase 0 (0-10s) - Initialization & Home**:
        *   **RECORD HOME (P0)**: Record current `Lat0, Lon0`. This is the point we want to return to.
        *   Set `target_heading = 180.0` (Magnetic South).
        *   Engage thrusters at `50%` speed to stabilize.
    *   **Phase 1 (at 10s) - Record Start Point (P1)**:
        *   Record `Lat1, Lon1`.
    *   **Phase 2 (10s - 130s) - Calibration Leg**:
        *   Sail at `50%` speed maintaining magnetic `180.0°`.
        *   Navigation: **Compass only**.
    *   **Phase 3 (at 130s) - Record Calibration End Point (P2)**:
        *   Record `Lat2, Lon2`.
        *   **IMMEDIATE CALCULATION**: Calculate the GPS course from P1 to P2. Calculate the error vs 180.0°.
        *   **APPLY & STORE**: Update `compassCalc.compassOffset` and call `CompasOffset(&compassCalc, SET)`.
        *   **RE-INITIALIZE**: Call `InitCompass()` to ensure the new offset is active.
    *   **Phase 4 (130s - 260s) - Return Leg (Verification)**:
        *   Set `target_heading = 0.0` (Magnetic North) to return towards the starting point.
        *   Use the **newly calibrated `compassOffset`**.
        *   **STABILIZATION (130s - 140s)**: Allow the buoy 10 seconds to turn around and stabilize its speed and rudder.
        *   **RECORD RETURN START (P2_stable)**: At 140s, record `Lat2_stable, Lon2_stable` to use for the return calculation.
        *   Sail for another 120 seconds (140s - 260s) using only the compass.
    *   **Phase 5 (at 260s) - Record Final Point (P3)**:
        *   Record `Lat3, Lon3`.
        *   **VALIDATE**: Calculate the GPS track from `P2_stable` to `P3`. 
    *   **Phase 6 (Final) - Return Home**:
        *   If the validation error is within a reasonable range (informative), the buoy should now engage its standard navigation logic.
        *   Set `targetLat = Lat0, targetLon = Lon0` (The Home position).
        *   Navigate back to the starting point using the fully calibrated GPS + Compass system.
        *   Once within range (e.g., 2m), stop thrusters and return to `IDLE` (7).

## 4. Calculation & Validation
*   **Protocol Note**: Since the buoy moves too slowly for reliable real-time GPS Course-Over-Ground (COG), all validation must be done using point-to-point coordinate math.
*   **Leg 1 Analysis (Calibration)**:
    *   `GPS_Course_1 = calculateAngle(Lat1, Lon1, Lat2, Lon2)`.
    *   `New_Offset = GPS_Course_1 - 180.0`. This aligns the 180° Magnetic heading with the actual GPS path taken.
*   **Leg 2 Analysis (Verification)**:
    *   `GPS_Course_2 = calculateAngle(Lat2, Lon2, Lat3, Lon3)`.
    *   `Validation_Error = abs(GPS_Course_2 - 0.0)` (normalized). 
*   **Leg 3 (Navigation)**: 
    *   The final leg back to P0 serves as the real-world test of the autonomous station-keeping capability with the fresh calibration.
*   **Completion**:
    *   Log `GPS_Course_1`, `GPS_Course_2`, and `New_Offset` to Serial. Play a completion tone once the buoy is back at P0.

## 5. Safety
*   **Abort**: Any `IDLE` or `LOCK` command from the user must instantly terminate the calibration and stop the motors.
*   **Fence**: If the buoy detects it is sailing into a known "danger zone" (if implemented) or if GPS signal is lost for > 5 seconds, abort.

## 6. Implementation Steps
1. Define `INFIELD_OFFSET_CALIBRATE` in `RoboCompute`.
2. Update `RobobuoyTop` to route the new command.
3. Implement the timer/phase logic in `RobobuoySub`.
4. Integrate the GUI button in `RoboControl.py`.

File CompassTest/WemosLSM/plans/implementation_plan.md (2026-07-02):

# Project Design Document & Implementation Plan: WemosLSM

This document details the architecture and implementation plan for building and deploying the firmware and web companion app for the **Heltec Wireless Tracker** and **LSM303AGR** compass.

## 1. Objectives & Scope
The goal is to develop a highly polished, fully functional Arduino-based firmware that:
1. Calculates real-time **tilt-compensated heading** using accelerometer and magnetometer data from the LSM303AGR.
2. Supports **Hard-Iron** and **Soft-Iron Calibration** to eliminate magnetic distortions.
3. Hosts a high-performance **ESPAsyncWebServer** using **WebSockets** for real-time (30fps) client-server telemetry.
4. Renders **two comparative windroses** (Hard-Iron only vs. Hard + Soft-Iron) and a **dynamic 3D visualizer** (representing the physical tracker's movement in real-time) using Three.js on the frontend.
5. Performs the complex magnetometer calibration fitting calculations directly on the client browser, sending computed calibration matrices/offsets back to the ESP32 to be stored in non-volatile memory (**Preferences**).
6. Runs on the **Heltec Wireless Tracker (ESP32-S3)** with ST7735 TFT display and supports Over-The-Air (OTA) updates.

---

## 2. System Architecture

```
                       +---------------------------------------+
                       |       Heltec Wireless Tracker         |
                       |       (ESP32-S3 / ST7735 TFT)         |
                       +-------------------+-------------------+
                                           |
                    +----------------------+----------------------+
                    |                      |                      |
            I2C Bus |                      | WebSockets / HTTP    | Wi-Fi (LAN)
                    v                      v                      v
         +----------+----------+  +--------+---------+   +--------+--------+
         | LSM303AGR Sensor    |  | ESPAsyncWebSrv   |   | ArduinoOTA      |
         | Accel + Magnetometer|  | (SPIFFS / LittleFS)| | Over-The-Air    |
         +---------------------+  +--------+---------+   +-----------------+
                                           |
                                           v  WebSocket (Telemetry & Commands)
                                  +--------+---------+
                                  | Client Browser   |
                                  | Dashboard (HTML5)|
                                  +--------+---------+
                                           |
                                           |--- Windrose A (Hard-Iron only)
                                           |--- Windrose B (Hard & Soft-Iron)
                                           |--- Three.js 3D Orientation Cube
                                           |--- Calibration Math (JS matrix fit)
```

### 2.1. Hardware & Firmware Layers (C++)
- **PlatformIO + Arduino ESP32 Framework:** Standard toolchain configuration.
- **Sensor Drivers:** 
  - `Adafruit_LSM303_Accel` and `Adafruit_LSM303AGR_Mag` for raw values.
- **Display Driver:** `Adafruit_ST7735` to show current status/IP address.
- **Network Stack:**
  - `WiFi` for connecting to SSID: `NicE_WiFi`.
  - `ArduinoOTA` for over-the-air binary uploading.
  - `ESPAsyncWebServer` and `AsyncTCP` for high-throughput WebSocket transmission.
- **NVM Storage:**
  - `Preferences` (ESP32 native NVM API) to store/retrieve 3D hard-iron offsets ($V_{hi}$) and a $3\times3$ soft-iron compensation matrix ($W_{si}$).

### 2.2. Web Dashboard & Visualization Layers (HTML/CSS/JS)
- **HTML/CSS (SPIFFS/LittleFS):** Static assets stored locally on the ESP32, loaded once, and cached.
- **WebSockets:** Establishes a raw connection for transferring real-time packet data (JSON format) containing:
  - Raw Accelerometer ($x, y, z$)
  - Raw Magnetometer ($x, y, z$)
  - Calibrated Magnetometer ($x, y, z$)
  - Heading (Hard-Iron only), Heading (Hard + Soft), Roll, Pitch
- **UI Render Engine:**
  - **Three.js** (loaded via CDN or minified and stored locally) to render a 3D board/cube inside a bounding wireframe.
  - **HTML Canvas** to render the custom Dual Windroses.
- **Calibration Engine (Client-side JS):**
  - When the user clicks **Start Calibration**, the browser accumulates raw magnetometer points.
  - Mathematical fitting (such as least-squares ellipsoid fitting) is computed in JS. This solves for both the hard-iron offset vector ($3\times1$) and the soft-iron matrix ($3\times3$).
  - Once complete, clicking **Store Calibration** sends these computed coefficients back to the ESP32 via WebSocket.
  - The ESP32 writes them to `Preferences` and immediately applies them.

---

## 3. Project File Structure

```
WemosLSM/
├── platformio.ini         # PlatformIO Project Configuration
├── LSM_arduino.md         # Technical Specification (Markdown)
├── plans/
│   └── implementation_plan.md # This document
├── data/                  # Web Server Files (SPIFFS / LittleFS)
│   ├── index.html         # Dynamic windrose dashboard & 3D Three.js renderer
│   ├── calibrate.html     # Web calibration interface with calibration algorithm
│   └── style.css          # Visual styling for the dashboard
└── src/                   # C++ Source Code
    ├── main.cpp           # Main entrypoint, setup, loop
    ├── DisplayController.h # Display initialization and text drawing
    ├── SensorFusion.h     # Compass reading, tilt compensation, math calculations
    └── WebPortal.h        # WiFi, WebServer, WebSockets, OTA and NVM management
```

---

## 4. Implementation Steps

### Phase 1: PlatformIO Setup & Configuration
- Create `platformio.ini` with correct ESP32-S3 board configurations (specifically for the Heltec Wireless Tracker).
- Add external dependencies (`Adafruit LSM303DLHC`, `Adafruit BusIO`, `Adafruit GFX`, `Adafruit ST7735`, `ESPAsyncWebServer`, `AsyncTCP`).
- Configure partitions to support both SPIFFS/LittleFS and OTA.

### Phase 2: Sensor and Display Control (C++)
- Implement initialization routines for the ST7735 display (enable power via `VEXT_PIN` (GPIO 3) and backlight via `BL_PIN` (GPIO 21)).
- Implement `SensorFusion` to read raw LSM303AGR accelerometer and magnetometer data.
- Write standard Hard-Iron and Soft-Iron calibration logic:
  $$\vec{M}_{calibrated} = W_{si} \times (\vec{M}_{raw} - \vec{V}_{hi})$$
- Apply tilt compensation to calculate roll, pitch, and yaw:
  - $\text{Roll} = \arctan2(Ay, Az)$
  - $\text{Pitch} = \arctan2(-Ax, \sqrt{Ay^2 + Az^2})$
  - Compasses yaw (heading) calculated using horizontal magnetometer projections.

### Phase 3: Web Server & Network Interface (C++)
- Set up WiFi connection with `NicE_WiFi` / `!Ni1001100110`.
- Initialize `ArduinoOTA` for OTA uploads.
- Implement SPIFFS/LittleFS filesystem serving `index.html` and other assets.
- Set up WebSocket endpoint (`/ws`) to stream JSON telemetry data at ~30Hz.
- Implement WebSocket commands:
  - `start_cal`: Starts sending raw uncalibrated values to client.
  - `save_cal`: Receives calibration coefficients from client and writes them to ESP32 Preferences NVM.

### Phase 4: Frontend Development (HTML/CSS/JS)
- Develop `index.html` with:
  - Two high-performance HTML5 Canvas Windroses.
  - A Three.js 3D viewport containing a 3D box representing the physical tracker.
  - An easy-to-use menu to navigate to `calibrate.html`.
- Develop `calibrate.html` with:
  - An algorithm to collect magnetic field points and compute a 3D ellipsoid fit.
  - Visual feedbacks of calibration progress.
  - A button to submit the calculated factors back to the device.

---

## 5. Testing & Verification Strategy
1. **Compilation Validation:** Ensure PlatformIO successfully compiles the C++ code without any warnings or type safety violations.
2. **Local Hardware Verification (First Upload):**
   - Flash via USB interface.
   - Monitor Serial output to verify connection to Wi-Fi.
   - Verify TFT display lights up and shows IP address.
3. **Sensor Calibration Validation:**
   - Verify raw magnetic data matches expected patterns (circular/ellipsoidal orbit in 3D).
   - Test calibration fit accuracy: Windrose B should match magnetic north perfectly as the tracker is rotated, while Windrose A shows distortion errors.
4. **OTA Verification:**
   - Modify the TFT displayed version.
   - Upload via OTA to verify the PlatformIO OTA toolchain works seamlessly.

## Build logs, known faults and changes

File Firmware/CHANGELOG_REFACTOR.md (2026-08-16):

# Robobuoy Firmware Refactor Summary

This document summarizes the changes made to the Robobuoy firmware ecosystem to improve stability, communication integrity, and memory safety.

## Recent Changes (March 25, 2026)

### 1. ESC & Motor Control (Sub)
- **LED Optimization**: Optimized the `EscTask` to only update the `ledPwr` queue when speeds or colors actually change, reducing unnecessary task context switching.
- **Dynamic LED Feedback**: Refactored LED color mapping into a unified `calculateLedColor` function, providing real-time visual feedback of motor thrust (Green for forward, Red for reverse).

### 2. Buzzer System Improvements (Top & Sub)
- **Sequence Integrity**: Updated `buzzerTask` to only pull new commands from the queue once the current beep sequence (including repeats) has fully completed.
- **Hardware Safety**: Explicitly set the buzzer pin to `LOW` after detaching the PWM signal. This prevents potential DC static voltage and audible "hum" when the buzzer is idle.
- **Startup Feedback**: Added distinctive startup beeps to both Top and Sub units for immediate audio confirmation of system boot.

### 3. Communication & Protocols
- **Sub Wakeup Logic**: Implemented a `WAKEUP` command. The Top unit now automatically sends a wakeup signal when transitioning from `IDLE` to an active state, ensuring the Sub is ready for commands.
- **Power Limit Configuration**: Added support for `MAXMINPWR` and `MAXMINPWRSET` commands, allowing for remote retrieval and configuration of motor power limits.
- **Enhanced Diagnostics**: Added detailed serial timeout logging on the Sub, reporting ESC heartbeat and task status when communication is lost.

### 4. Navigation & Logic (Sub)
- **Precision Locking**: Reduced the `tgDist` (target distance) threshold for automatic station-keeping lock from 1.5m to 1.0m, improving position hold accuracy.

### 5. Display & Touch (RoboDisplay_AI)
- **Touchscreen Fix**: Corrected XPT2046 touchscreen SPI bus sharing and coordinate mapping for improved UI reliability on AI-enabled display modules.

### 6. UDP Monitor (Python Tooling)
- **Visual Overlays**: Added real-time Target Distance and PID I-term (Wind Proxy) text overlays directly on the windrose canvas for at-a-glance monitoring.
- **GPS Vector Support**: Implemented a new "GPS Direction" vector (black arrow) with a 5-second stabilization filter to visualize GPS-derived heading.
- **Speed Limit Configuration**: Added a "Speed Limits" section to the setup window, allowing remote configuration of `maxSpeed` and `minSpeed`.
- **UI Polish**: 
    - Displaying buoy IP addresses in the frame headers.
    - Improved vector legend and color-coding for better clarity.
    - Thread-safe logging and automated log cleanup to prevent UI lag.

### 7. LoraController Standardisation
- **Library Consistency**: Updated `LoraController` to use standard `<RoboCompute.h>` includes, aligning with the centralized dependency model.
- **ID Selection Fix**: Resolved a logic error in `getNextValidID` where the iteration would return prematurely during buoy ID cycling.

## 1. Architectural Changes: Centralized Dependency
- **Direct Source Compilation**: Updated `platformio.ini` for all projects (`Top`, `Sub`, `Base`, `Remote`, `LoraController`) to use `lib_extra_dirs` pointing to `../RoboDependency`.
- **Benefit**: This ensures that all projects compile against the master version of `RoboCompute` and `RoboTone` directly. Changes made to the central library are immediately reflected across all projects without manual copying.

## 2. Master Library Improvements (`RoboCompute`)
- **Pointer-Based API**: Refactored major functions (`PidDecode`, `PidEncode`, `hooverPid`, `CalcRemoteRudderBuoy`) to use `RoboStruct*` pointers.
  - **Why**: Prevented expensive memory copying of the large `RoboStruct` and ensured that parameter updates (like PID tuning) persist across function calls.
- **Adaptive Station Keeping (I-Driven Stiffening)**: Implemented a wind-proxy logic in `hooverPid`.
  - **Logic**: The loop uses the Integral (I) term to estimate wind force. If the I-term is high (strong wind), the Proportional (P) gain is automatically doubled to "stiffen" the response.
- **3-Buoy Start Line Logic**: Updated `recalcStartLine` to handle complex layouts.
  - **Feature**: Automatically identifies the "HEAD" (upwind) buoy and repositions the remaining two "DOWNWIND" buoys symmetrically around their midpoint, perpendicular to the wind.
- **Telemetry Decoding Fixes**: Resolved critical bugs in `RoboDecode`:
  - Fixed `WINDDATA` and `TOPDATA` where array indices were duplicated, causing telemetry data to be overwritten or lost.
  - Fixed `PID` decoding to correctly assign P, I, and D terms to their respective variables.
- **Safety**: Fixed an out-of-bounds array access in `calcTrackPos`.

## 3. Communication Integrity
- **UDP Double CRC Fix**: Removed a redundant CRC encoding step in `topwifi.cpp`.
  - **Problem**: Packets were being encoded twice (`$$data*CRC*CRC`), making them unreadable.
- **Serial Reliability**: Fixed a bug in `RobobuoySub/sercom.cpp` where `random(1200, 750)` was called. 
  - **Fix**: Swapped to `random(750, 1200)` as the Arduino `random()` function requires `min < max`. This ensures proper retransmission timing.

## 4. GPS System Overhaul (`RobobuoyTop`)
- **Thread Safety**: Refactored `RouteToPoint` to use standalone mathematical functions instead of the shared `TinyGPSPlus` object.
  - **Why**: Prevented race conditions between the asynchronous GPS task and the main logic loop.
- **Outlier Recovery**: Improved `handleGpsData` in `main.cpp`.
  - **Feature**: Added a "persistent outlier" check. If the GPS receives 30 consecutive "jumps" >50m, it now accepts the new position. This allows the buoy to recover if it is physically moved while powered on.

## 5. Task Performance & Stability
- **Serial Robustness**: 
  - Implemented `Serial.readStringUntil('
')` with a 100ms timeout in both projects.
  - **Benefit**: Prevents tasks from stalling if a character is missed or a packet is malformed.
- **Non-Blocking State Machines**: Refactored `buzzerTask` and `CompassTask`.
  - **Fix**: Replaced long `vTaskDelay` and hardware busy-waits with state-machine logic.
  - **Benefit**: The system remains responsive to high-priority commands (like E-Stops or new beep requests) even during long operations.
- **Queue Optimization**: Switched to `xQueueOverwrite` for high-frequency telemetry (Compass, GPS).
  - **Benefit**: Ensures the main loop always processes the freshest data and prevents queue-full blocking.
- **LED Efficiency**: Added a 10ms timeout to `LedTask` queue reads to prevent CPU "spinning" (busy-waiting) when idle.

## 6. Hardware & Logic Safety
- **ESC Jitter Removal**: Corrected the ramping logic in `esc.cpp` that caused a ±1 pulse-width oscillation when the motors were supposed to be stationary.
- **Type Safety**: Fixed a critical struct mismatch in the `Sub` loop where `PwrData` was being sent to a queue expecting `LedData`.
- **I2C Reliability**: Added explicit `Wire.begin()` calls and verified sensor initialization to prevent bus hangs.

## 7. Memory Management
- **Stack Safety**: Increased `buzzerTask` stack size from 1000 to 2048 bytes.
- **Auto-Migration**: Added logic to `initMemory` to automatically detect and fix the legacy `Doclat` typo, moving existing coordinates to the corrected `Docklat` key.
- **Hardware Binding**: Both projects now use the hardware MAC address to verify memory ownership, ensuring defaults are re-applied if the processor is swapped.
- **Signature Sync**: Synchronized all `.h` and `.cpp` files to ensure function signatures match, resolving multiple linker and compiler errors.

## 8. Future Feature Plan: Dynamic Compass Offset Calibration
... (existing content) ...

## 9. Proposal: Optimized Navigation Strategy for Dual-Thruster Buoys
Given the dual-thruster configuration (differential thrust) with forward/reverse capability, the following strategy is proposed for transitioning to a new waypoint (`tgLat`, `tgLng`).

### Objective:
Minimize "hunting" (oscillating around the course) and ensure the buoy arrives at the target coordinates with the correct heading, regardless of its starting orientation.

### Recommended Implementation: Three-Phase Steering logic

#### Phase 1: Zero-Radius Rotation (The "Pivot")
*   **Trigger**: Angle error to waypoint > 30°.
*   **Action**: Use the thrusters in **opposing directions** (e.g., Left Forward, Right Reverse) to rotate the buoy on its center axis.
*   **Advantage**: This is the most energy-efficient way to correct a large heading error. It prevents the buoy from sailing a large, inefficient arc while trying to turn.

#### Phase 2: Differential Forward Translation (The "Transit")
*   **Trigger**: Angle error < 30° and distance > `holdRad`.
*   **Action**: Both thrusters run forward with a **speed bias** based on the PID output.
    *   `BaseSpeed` = Calculated by Speed PID.
    *   `LeftThruster` = BaseSpeed - RudderPID_Output.
    *   `RightThruster` = BaseSpeed + RudderPID_Output.
*   **Advantage**: Maintains forward momentum while making fine-grained course corrections.

#### Phase 3: High-Precision Station Keeping (The "Hover")
*   **Trigger**: Distance < `holdRad`.
*   **Action**: Switch to a sensitive "Pulse" mode or use very low duty cycles.
*   **Refinement**: If the buoy overshoots, it should use **Reverse Thrust** immediately rather than trying to turn 180 degrees. The dual-thruster setup allows for "backing up" which is much more stable for maintaining a precise coordinate.

### Safety & Efficiency Considerations:
1.  **Thrust Asymmetry Compensation**: Implement a small scaling factor if one motor is slightly more powerful than the other.
2.  **Wind-Vane Mode**: In high winds, the buoy should prioritize keeping its "nose" (the most aerodynamic/hydrodynamic profile) into the wind, even if it means sailing slightly "sideways" to the waypoint.
3.  **Deadband**: Implement a 2-3 degree "deadband" where no steering correction is made to prevent motor jitter and save battery.

---
**Status**: All projects are now compiling correctly and are functionally robust.

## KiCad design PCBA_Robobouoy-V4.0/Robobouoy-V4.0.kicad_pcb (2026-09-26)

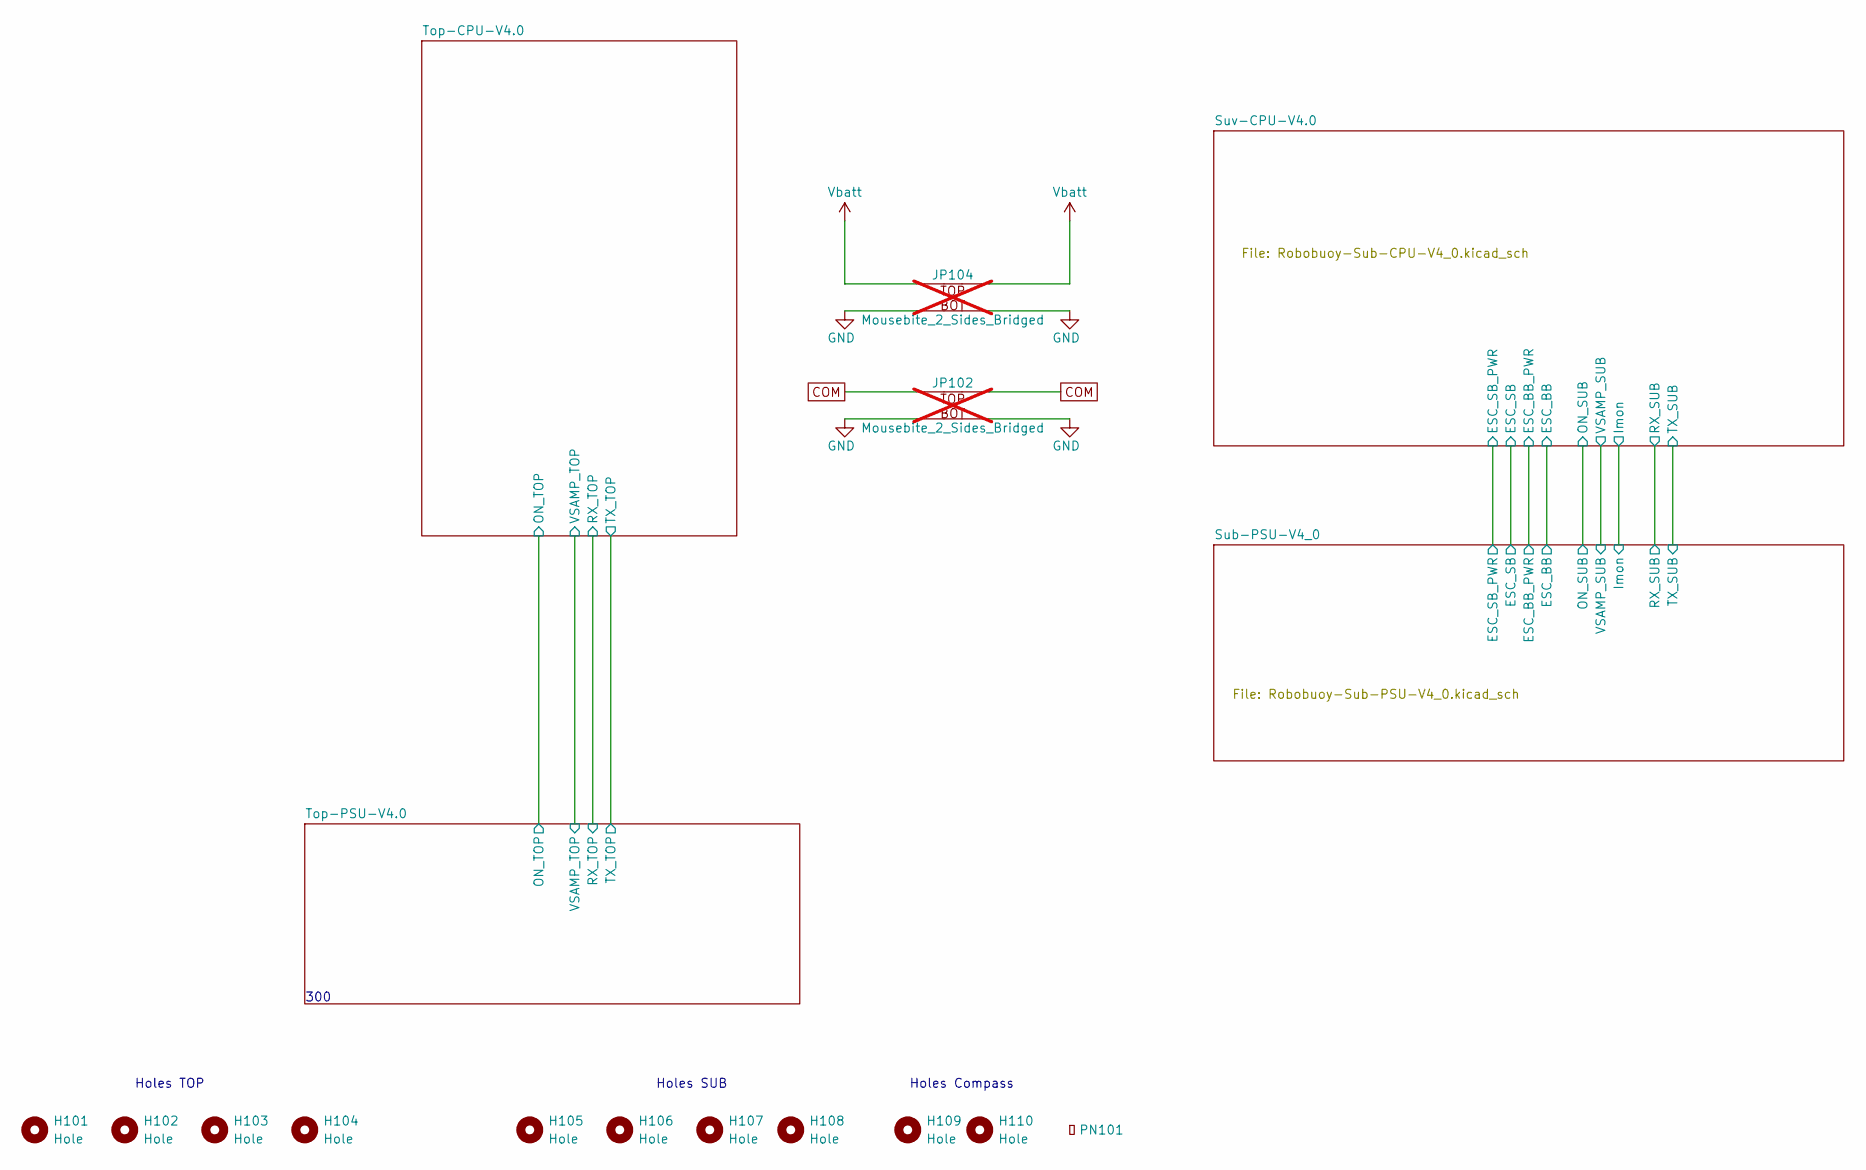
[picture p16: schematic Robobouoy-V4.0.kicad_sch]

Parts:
H101, H102, H103, H104, H105, H106, H107, H108, H109, H110: Hole; Hole_3.1mm
JP102, JP104: Mousebite_2_Sides_Bridged; MousebitConnectorDoubleSided; not fitted
PN101: Part_Num_JLCPCB

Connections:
COM: JP102.1 (A), JP102.2 (B); also elsewhere on the board
GND: JP102.3 (C), JP102.4 (D), JP104.3 (C), JP104.4 (D); also elsewhere on the board
Vbatt: JP104.1 (A), JP104.2 (B); also elsewhere on the board

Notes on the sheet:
Holes TOP
300
Holes SUB
Holes Compass

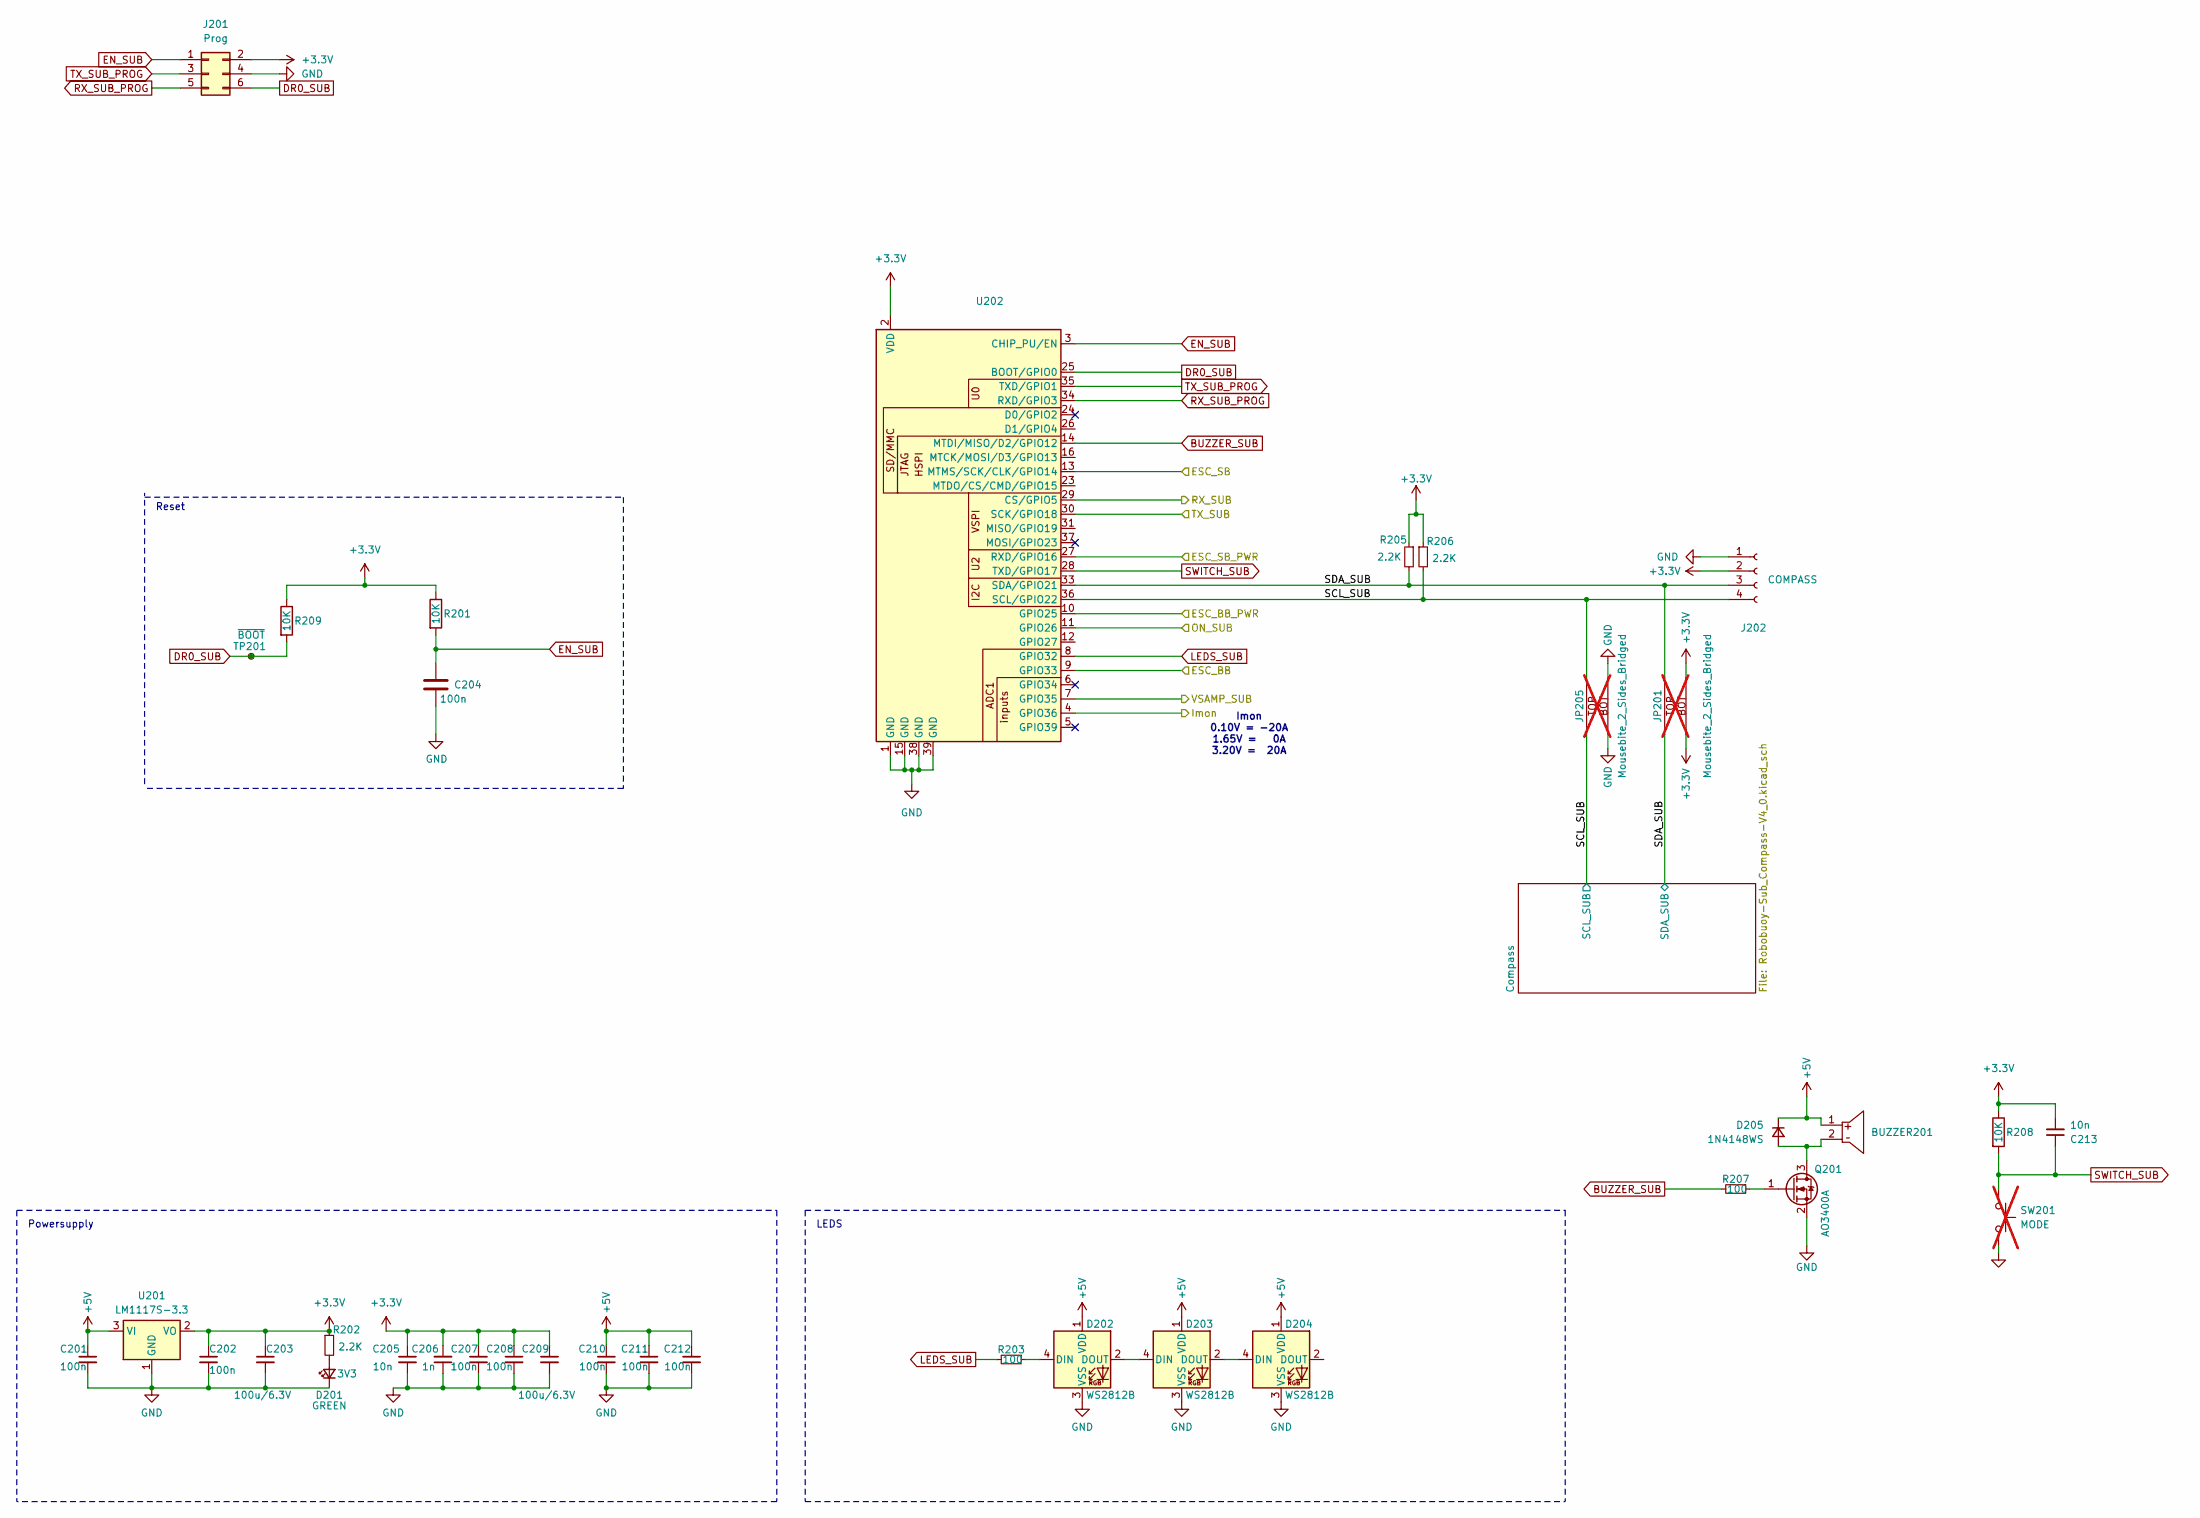
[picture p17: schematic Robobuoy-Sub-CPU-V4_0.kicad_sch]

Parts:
BUZZER201: CY-12085G-3016-P4; BUZ-TH_BD12.0-P6.50-D0.6-FD; MPN Cy-12085G-3016-P4; LCSC Part C968749
C201, C202, C204, C207, C208, C210, C211, C212: 100n; C_0603; LCSC C14663
C203, C209: 100u/6.3V; C_1206_3216Metric; LCSC C16133
C205, C213: 10n; C_0603; LCSC C57112
C206: 1n; C_0603; LCSC C1588
D201: GREEN; LED_0603_1608Metric; LCSC C12624
D202, D203, D204: WS2812B; LED_WS2812B_PLCC4_5.0x5.0mm_P3.2mm; LCSC C2843785
D205: 1N4148WS; D_SOD-323_1.8x1.4x1.15; LCSC C2128
J201: Prog; IDC_2x3_1.27mm; LCSC C42372545
J202: COMPASS; JST_XH_B4B-XH-A_1x04_P2.50mm_Vertical; LCSC C5341203
JP201, JP205: Mousebite_2_Sides_Bridged; MousebitConnectorDoubleSided; not fitted
Q201: AO3400A; SOT-23; LCSC C20917
R201, R208, R209: 10K; R_0603; Farnell 2331736
R202, R205, R206: 2.2K; R_0603; LCSC C4190
R203, R207: 100; R_0603; LCSC C22775
SW201: MODE; Header_1x02_P2.54_Jumper; not fitted
TP201: ~{BOOT}; Testpad_1
U201: LM1117S-3.3; SOT223; LCSC C6186
U202: ESP32-WROOM-32E_(visible_peripherals); ESP32-WROOM-32; LCSC C82899

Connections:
+3.3V: C202.1, C203.1, C205.1, C206.2, C207.1, C208.1, C209.1, C213.2, J201.2, J202.2, JP201.3 (C), JP201.4 (D), R201.1, R202.1, R205.1, R206.1, R208.1, R209.1, U201.2 (VO), U202.2 (VDD); also elsewhere on the board
+5V: BUZZER201.1, C201.1, C210.1, C211.1, C212.1, D202.1 (VDD), D203.1 (VDD), D204.1 (VDD), D205.1 (K), U201.3 (VI); also elsewhere on the board
/Sub-PSU-V4_0/ESC_BB: U202.9 (GPIO33); also elsewhere on the board
/Sub-PSU-V4_0/ESC_BB_PWR: U202.10 (GPIO25); also elsewhere on the board
/Sub-PSU-V4_0/ESC_SB: U202.13 (MTMS/SCK/CLK/GPIO14); also elsewhere on the board
/Sub-PSU-V4_0/ESC_SB_PWR: U202.27 (RXD/GPIO16); also elsewhere on the board
/Sub-PSU-V4_0/Imon: U202.4 (GPIO36); also elsewhere on the board
/Sub-PSU-V4_0/ON_SUB: U202.11 (GPIO26); also elsewhere on the board
/Sub-PSU-V4_0/RX_SUB: U202.29 (CS/GPIO5); also elsewhere on the board
/Sub-PSU-V4_0/TX_SUB: U202.30 (SCK/GPIO18); also elsewhere on the board
/Sub-PSU-V4_0/VSAMP_SUB: U202.7 (GPIO35); also elsewhere on the board
/Suv-CPU-V4.0/SCL_SUB: J202.4, JP205.1 (A), JP205.2 (B), R206.2, U202.36 (SCL/GPIO22); also elsewhere on the board
/Suv-CPU-V4.0/SDA_SUB: J202.3, JP201.1 (A), JP201.2 (B), R205.2, U202.33 (SDA/GPIO21); also elsewhere on the board
BUZZER_SUB: R207.2, U202.14 (MTDI/MISO/D2/GPIO12)
DR0_SUB: J201.6, R209.2, TP201.1 (1_1), U202.25 (BOOT/GPIO0)
EN_SUB: C204.1, J201.1, R201.2, U202.3 (CHIP_PU/EN)
GND: C201.2, C202.2, C203.2, C204.2, C205.2, C206.1, C207.2, C208.2, C209.2, C210.2, C211.2, C212.2, D201.1 (K), D202.3 (VSS), D203.3 (VSS), D204.3 (VSS), J201.4, J202.1, JP205.3 (C), JP205.4 (D), Q201.2 (S), SW201.1, U201.1 (GND), U202.1 (GND), U202.15 (GND), U202.38 (GND), U202.39 (GND); also elsewhere on the board
LEDS_SUB: R203.2, U202.8 (GPIO32)
unnamed: D201.2 (A), R202.2
unnamed: D202.4 (DIN), R203.1
unnamed: D202.2 (DOUT), D203.4 (DIN)
unnamed: D203.2 (DOUT), D204.4 (DIN)
unnamed: BUZZER201.2, D205.2 (A), Q201.3 (D)
unnamed: Q201.1 (G), R207.1
RX_SUB_PROG: J201.5, U202.34 (RXD/GPIO3)
SWITCH_SUB: C213.1, R208.2, SW201.2, U202.28 (TXD/GPIO17)
TX_SUB_PROG: J201.3, U202.35 (TXD/GPIO1)

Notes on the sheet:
LEDS
Imon 0.10V = -20A 1.65V = 0A 3.20V = 20A
Powersupply
Reset

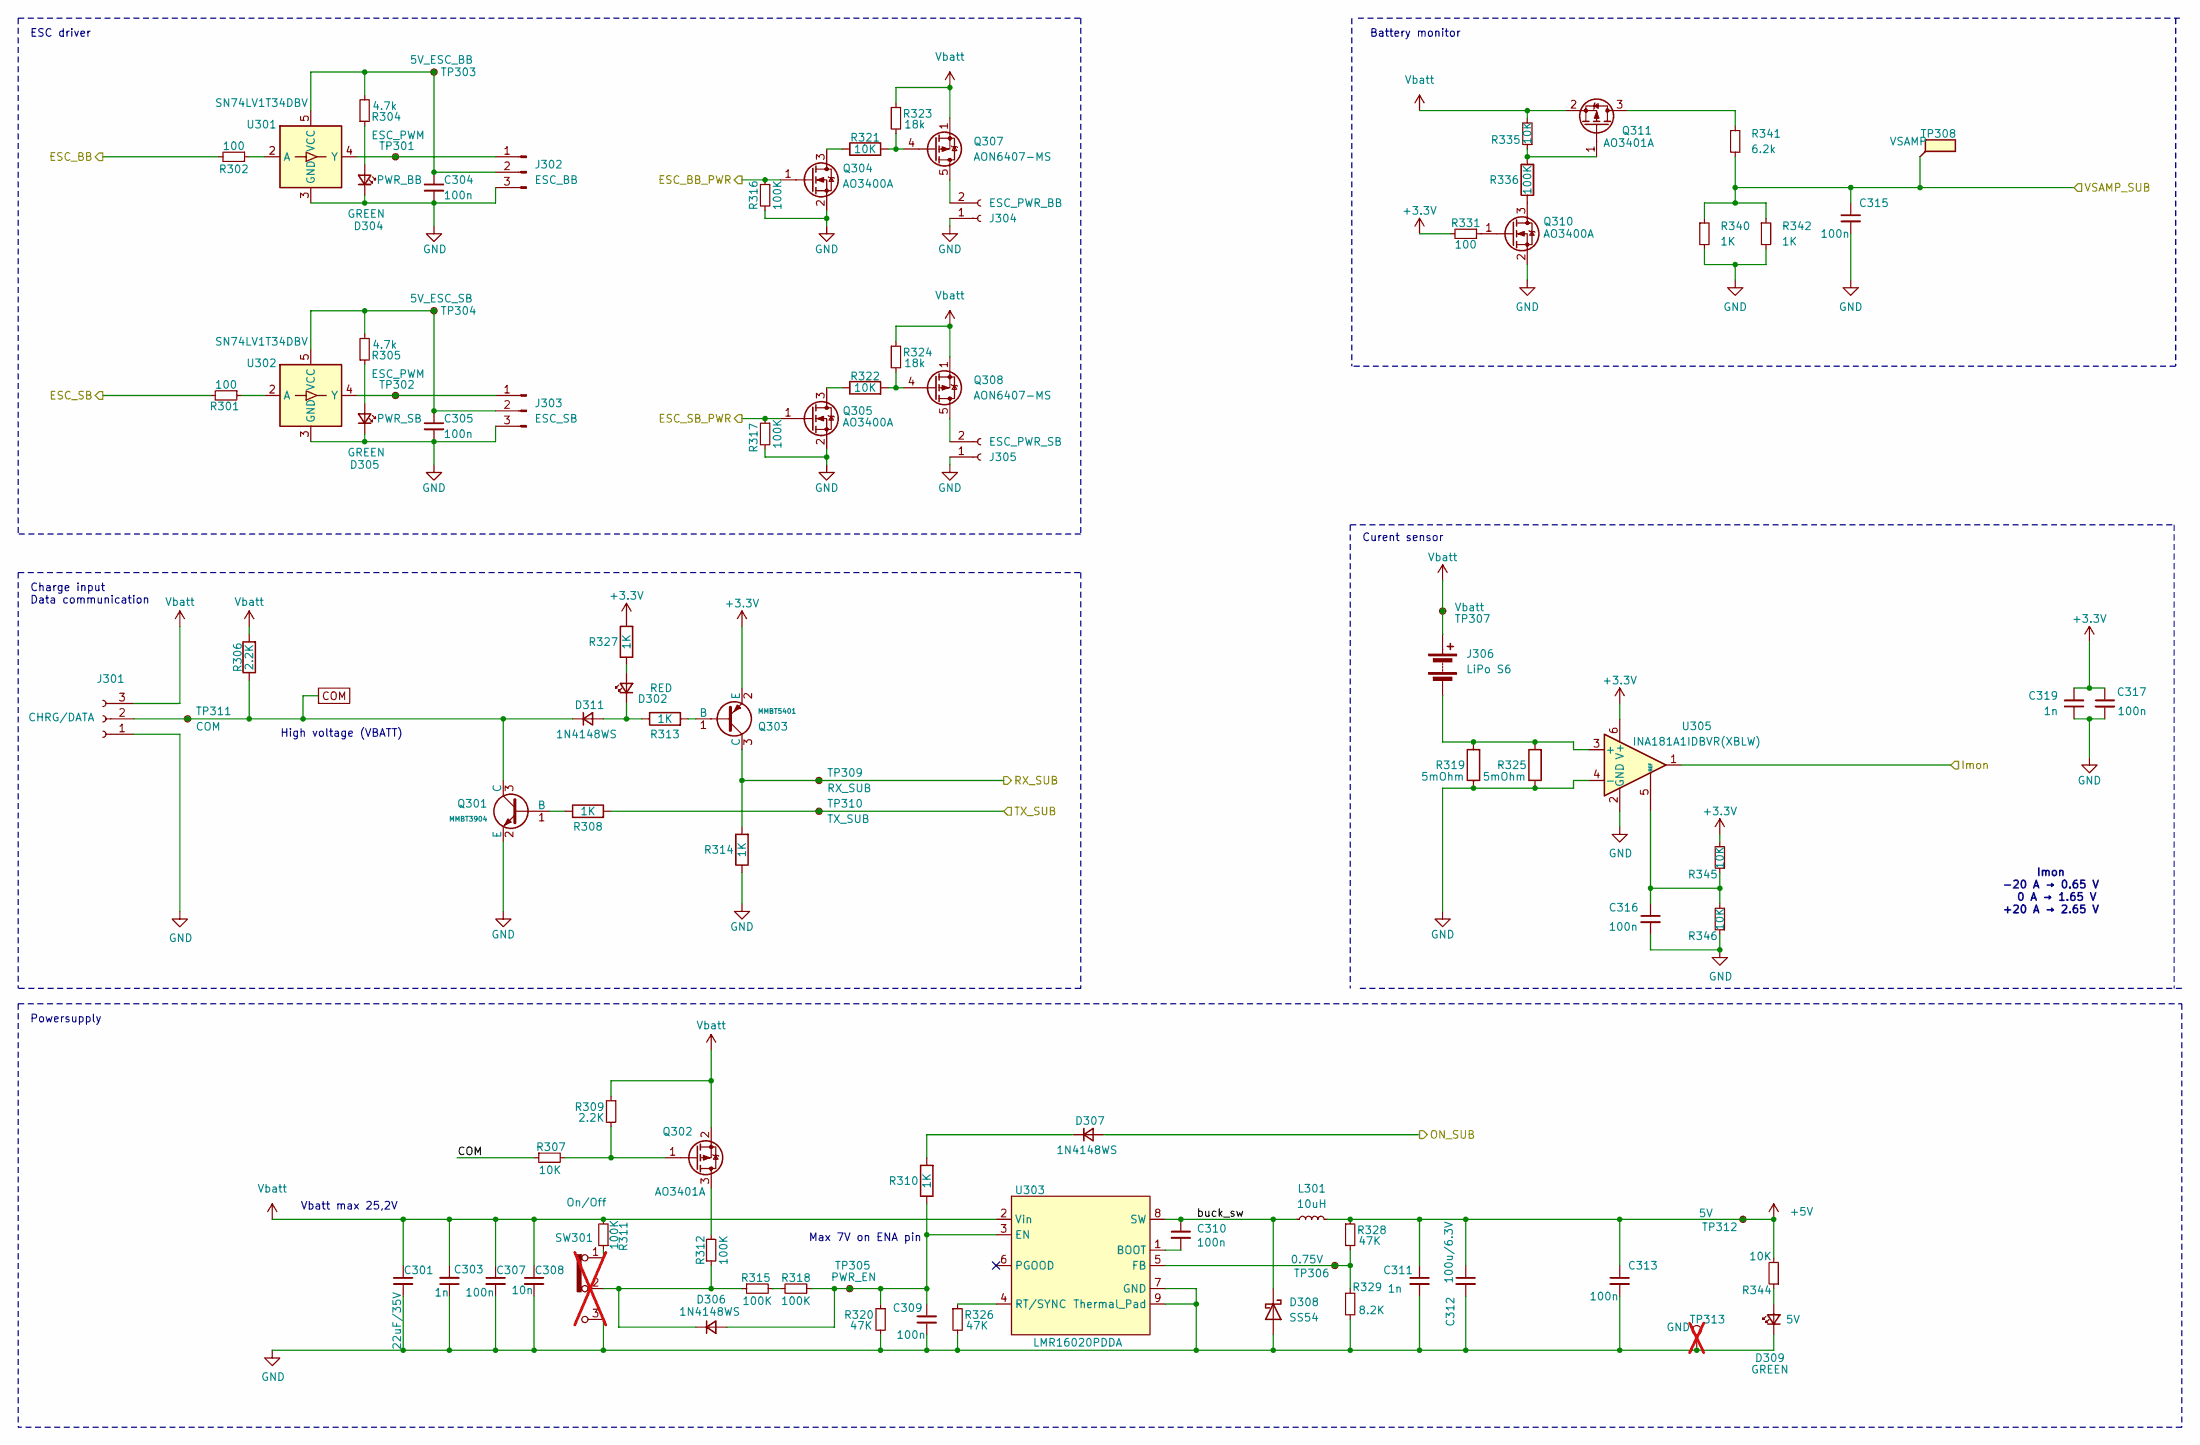
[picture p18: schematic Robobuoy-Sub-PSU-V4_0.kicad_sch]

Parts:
C301: 22uF/35V; C_1206_3216Metric; LCSC C6119969
C303, C311, C319: 1n; C_0603; LCSC C1588
C304, C305, C307, C309, C310, C313, C315, C316, C317: 100n; C_0603; LCSC C14663
C308: 10n; C_0603; LCSC C57112
C312: 100u/6.3V; C_1206_3216Metric; LCSC C16133
D302: RED; LED_0603_1608Metric; LCSC C2286
D304, D305, D309: GREEN; LED_0603_1608Metric; LCSC C2286
D306, D307, D311: 1N4148WS; D_SOD-323_1.8x1.4x1.15; LCSC C2128
D308: SS54; D_SMA; LCSC C22452
J301: CHRG/DATA; MR60PB-M; LCSC C53087234
J302: ESC_BB; JST_XH_B3B-XH-A_1x03_P2.50mm_Vertical; LCSC C5341202
J303: ESC_SB; JST_XH_B3B-XH-A_1x03_P2.50mm_Vertical; LCSC C5341202
J304: ESC_PWR_BB; AMASS_XT60PB-F_1x02_P7.20mm_Vertical; LCSC C19268038
J305: ESC_PWR_SB; AMASS_XT60PB-F_1x02_P7.20mm_Vertical; LCSC C19268038
J306: LiPo S6; AMASS_XT60PB-M_1x02_P7.20mm_Vertical; LCSC C19268037
L301: 10uH; L_6.6x7.0mm; LCSC C2894722
Q301: MMBT3904; Q_SOT-23; Part MMBT3904; LCSC C7420353
Q302, Q311: AO3401A; SOT-23; LCSC C15127
Q303: MMBT5401; Q_SOT-23; Part MMBT5401; LCSC C7420356
Q304, Q305, Q310: AO3400A; SOT-23; LCSC C20917
Q307, Q308: AON6407-MS; AO_DFN-8-1EP_5.55x5.2mm_P1.27mm_EP4.12x4.6mm; LCSC C17702953
R301, R302, R331: 100; R_0603; LCSC C22775
R304, R305: 4.7k; R_0603; LCSC C4177
R306, R309: 2.2K; R_0603; LCSC C4190
R307, R321, R322, R335, R344, R345, R346: 10K; R_0603; LCSC C25804
R308, R310, R313, R314, R327, R340, R342: 1K; R_0603; LCSC C21190
R311, R312, R315, R316, R317, R318, R336: 100K; R_0603; LCSC C25803
R319, R325: 5mOhm; R_1206; LCSC C7419996
R320, R326, R328: 47K; R_0603; LCSC C25819
R323, R324: 18k; R_0603; LCSC C25810
R329: 8.2K; R_0603; LCSC C25981
R341: 6.2k; R_0603; LCSC C4260
SW301: On/Off; Header_1x03_P2.54_Male; LCSC C2937625; not fitted
TP301, TP302: ESC_PWM; Testpad_1
TP303: 5V_ESC_BB; Testpad_1
TP304: 5V_ESC_SB; Testpad_1
TP305: PWR_EN; Testpad_1
TP306: 0.75V; Testpad_1
TP307: Vbatt; Testpad_1
TP308: VSAMP; Testpad_1
TP309: RX_SUB; Testpad_1
TP310: TX_SUB; Testpad_1
TP311: COM; Testpad_1
TP312: 5V; Testpad_1
TP313: GND; Testpoint_0.9x1.5; not fitted
U301, U302: SN74LV1T34DBV; SOT-23-5; LCSC C100024
U303: LMR16020PDDA; SOIC-8-1EP_3.9x4.9mm_P1.27mm_EP2.41x3.81mm_ThermalVias; LCSC C190006
U305: INA181A1IDBVR(XBLW); SOT-23-6; LCSC C45351496

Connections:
+3.3V: C317.1, C319.2, Q303.2 (E), R327.2, R331.2, R345.2, U305.6 (V+); also elsewhere on the board
+5V: C311.1, C312.1, C313.1, L301.2, R328.1, R344.2, TP312.1 (1_1); also elsewhere on the board
/Sub-PSU-V4_0/ESC_BB: R302.2; also elsewhere on the board
/Sub-PSU-V4_0/ESC_BB_PWR: Q304.1 (G), R316.1; also elsewhere on the board
/Sub-PSU-V4_0/ESC_SB: R301.2; also elsewhere on the board
/Sub-PSU-V4_0/ESC_SB_PWR: Q305.1 (G), R317.1; also elsewhere on the board
/Sub-PSU-V4_0/Imon: U305.1; also elsewhere on the board
/Sub-PSU-V4_0/ON_SUB: D307.2 (A); also elsewhere on the board
/Sub-PSU-V4_0/RX_SUB: Q303.3 (C), R314.2, TP309.1 (1_1); also elsewhere on the board
/Sub-PSU-V4_0/TX_SUB: R308.2, TP310.1 (1_1); also elsewhere on the board
/Sub-PSU-V4_0/VSAMP_SUB: C315.1, R340.1, R341.2, R342.1, TP308.1 (1_1); also elsewhere on the board
/Sub-PSU-V4_0/buck_sw: C310.1, D308.1 (K), L301.1, U303.8 (SW)
COM: D311.1 (K), J301.2, Q301.3 (C), R306.1, R307.1, TP311.1 (1_1); also elsewhere on the board
GND: C301.2, C303.1, C304.2, C305.2, C307.2, C308.2, C309.2, C311.2, C312.2, C313.2, C315.2, C316.2, C317.2, C319.1, D304.1 (K), D305.1 (K), D308.2 (A), D309.1 (K), J301.1, J302.3, J303.3, J304.1, J305.1, Q301.2 (E), Q304.2 (S), Q305.2 (S), Q310.2 (S), R314.1, R316.2, R317.2, R319.1, R320.2, R325.1, R326.2, R329.2, R340.2, R342.2, R346.1, SW301.3, TP313.1 (1_1), U301.3 (GND), U302.3 (GND), U303.7 (GND), U303.9 (Thermal_Pad), U305.2 (GND), U305.4 (-); also elsewhere on the board
unnamed: D302.2 (A), R327.1
unnamed: D302.1 (K), D311.2 (A), R313.1
unnamed: D304.2 (A), R304.1
unnamed: D305.2 (A), R305.1
unnamed: C309.1, D306.2 (A), R310.1, R318.1, R320.1, TP305.1 (1_1), U303.3 (EN)
unnamed: D306.1 (K), R312.1, R315.1, SW301.2
unnamed: D307.1 (K), R310.2
unnamed: D309.2 (A), R344.1
unnamed: J302.1, TP301.1 (1_1), U301.4 (Y)
unnamed: C304.1, J302.2, R304.2, TP303.1 (1_1), U301.5 (VCC)
unnamed: J303.1, TP302.1 (1_1), U302.4 (Y)
unnamed: C305.1, J303.2, R305.2, TP304.1 (1_1), U302.5 (VCC)
unnamed: J304.2, Q307.5 (D)
unnamed: J305.2, Q308.5 (D)
unnamed: J306.1 (-), R319.2, R325.2, U305.3 (+)
unnamed: Q301.1 (B), R308.1
unnamed: Q302.3 (D), R312.2
unnamed: Q302.1 (G), R307.2, R309.2
unnamed: Q303.1 (B), R313.2
unnamed: Q304.3 (D), R321.1
unnamed: Q305.3 (D), R322.1
unnamed: Q307.4 (G), R321.2, R323.2
unnamed: Q308.4 (G), R322.2, R324.2
unnamed: Q310.3 (D), R336.1
unnamed: Q310.1 (G), R331.1
unnamed: Q311.3 (D), R341.1
unnamed: Q311.1 (G), R335.1, R336.2
unnamed: R311.1, SW301.1
unnamed: R315.2, R318.2
unnamed: R302.1, U301.2 (A)
unnamed: R301.1, U302.2 (A)
unnamed: C310.2, U303.1 (BOOT)
unnamed: R328.2, R329.1, TP306.1 (1_1), U303.5 (FB)
unnamed: R326.1, U303.4 (RT/SYNC)
unnamed: C316.1, R345.1, R346.2, U305.5 (REF)
Vbatt: C301.1, C303.2, C307.1, C308.1, J301.3, J306.2 (+), Q302.2 (S), Q307.1 (S), Q307.2 (S), Q307.3 (S), Q308.1 (S), Q308.2 (S), Q308.3 (S), Q311.2 (S), R306.2, R309.1, R311.2, R323.1, R324.1, R335.2, TP307.1 (1_1), U303.2 (Vin); also elsewhere on the board

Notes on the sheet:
Max 7V on ENA pin
Vbatt max 25,2V
ESC driver
Curent sensor
Powersupply
Charge input Data communication
Battery monitor
High voltage (VBATT)
Imon -20 A → 0.65 V 0 A → 1.65 V +20 A → 2.65 V

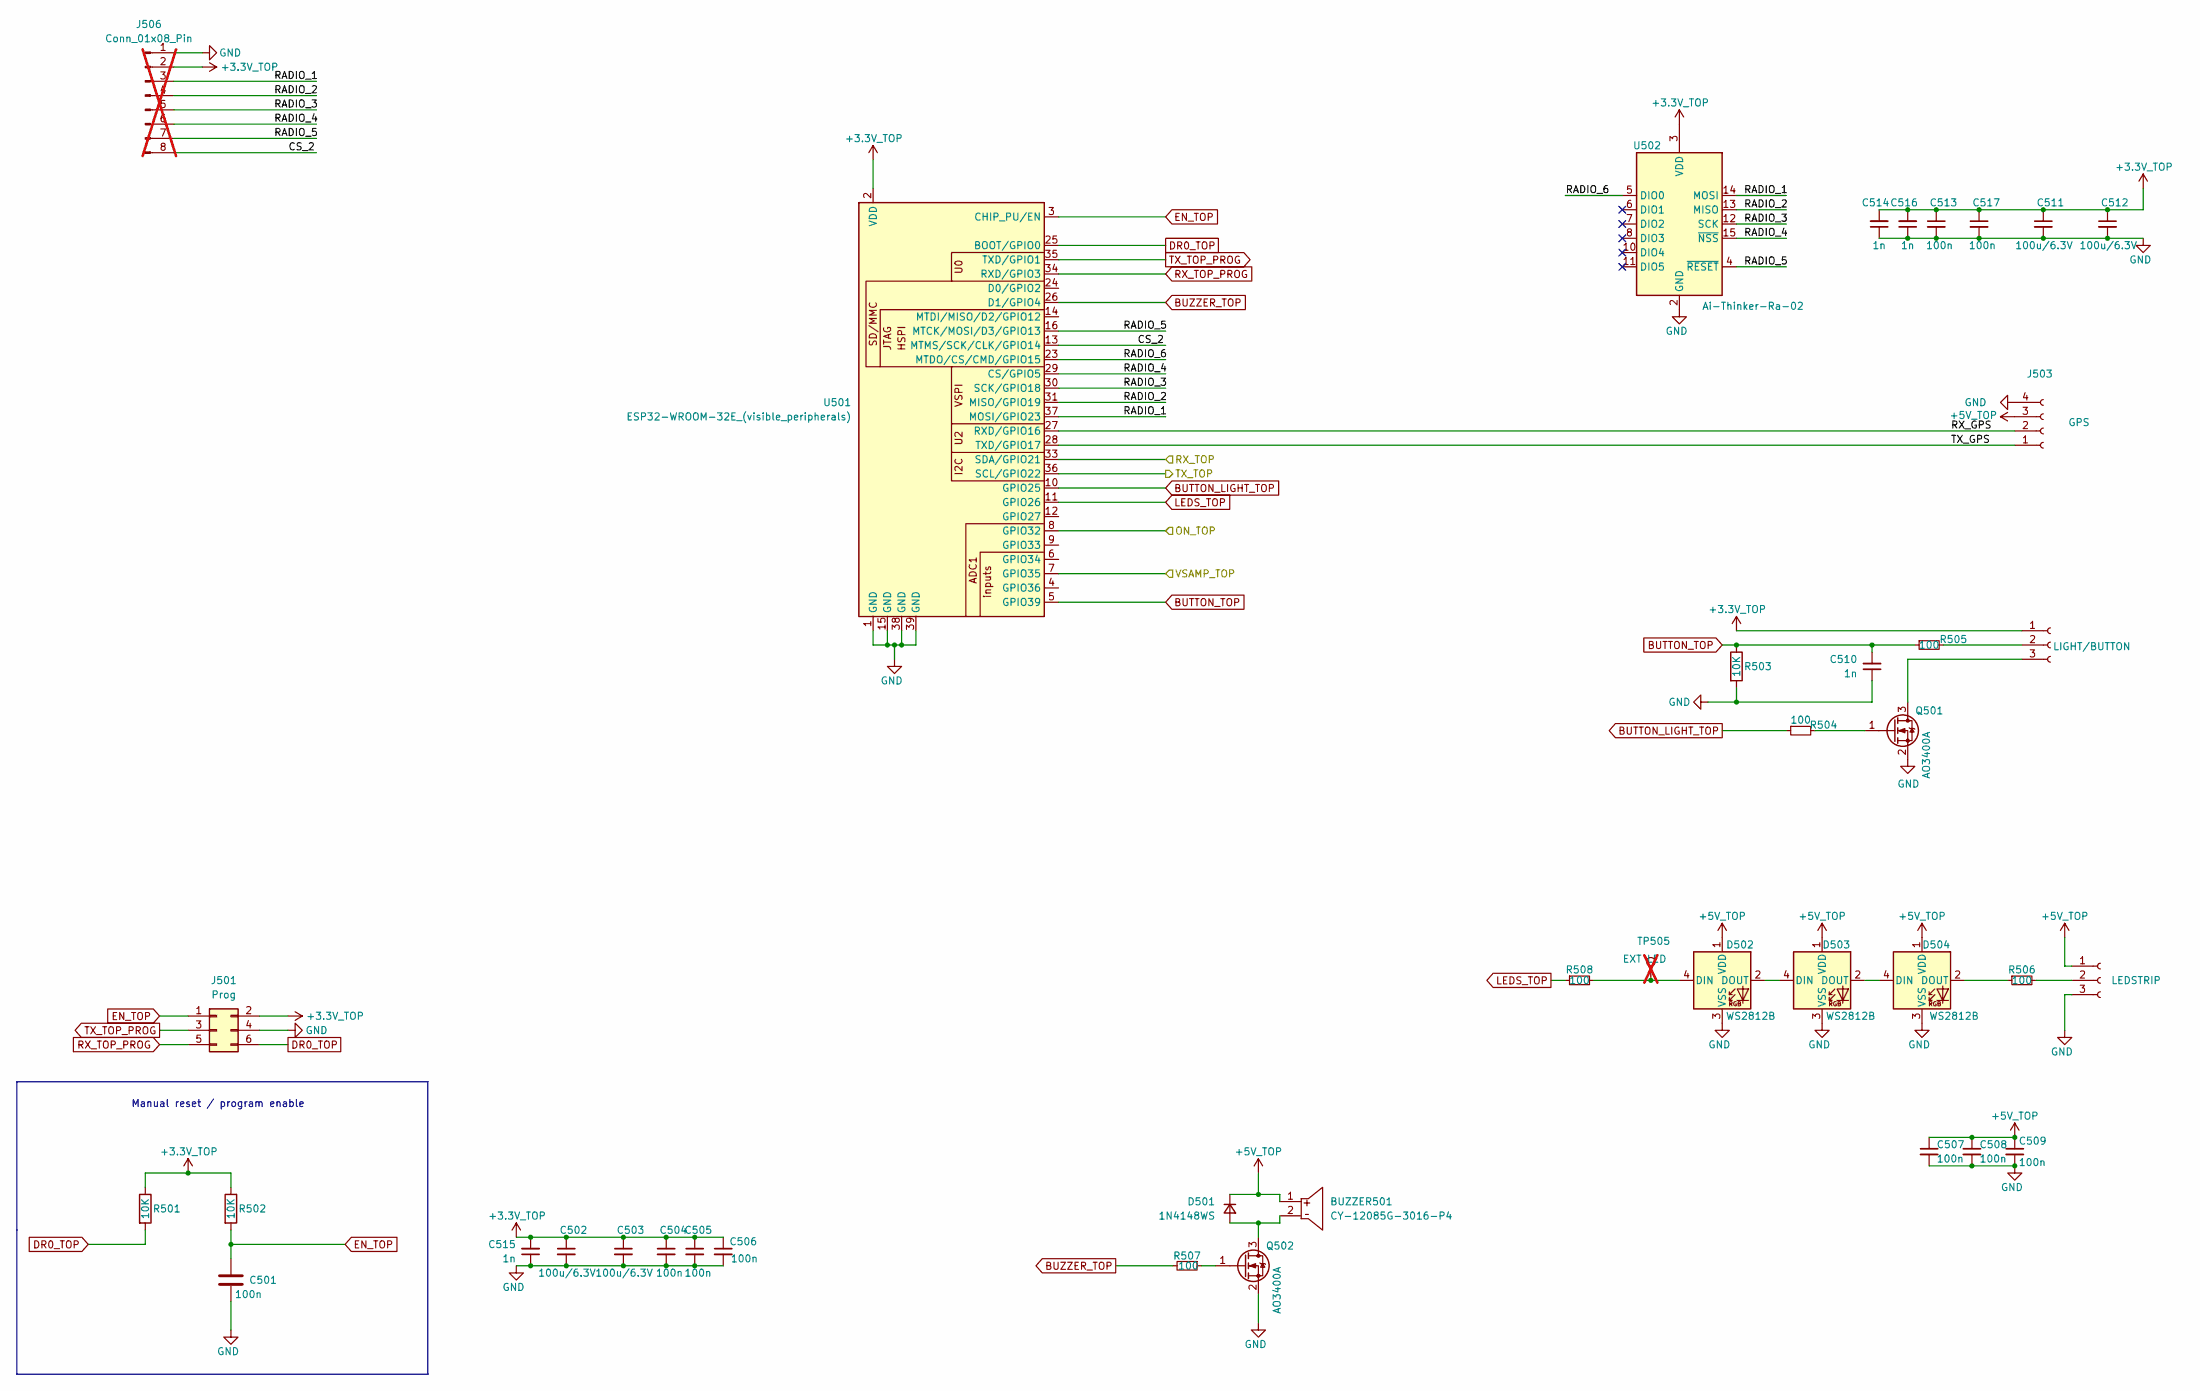
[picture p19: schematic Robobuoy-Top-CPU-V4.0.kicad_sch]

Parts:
BUZZER501: CY-12085G-3016-P4; BUZ-TH_BD12.0-P6.50-D0.6-FD; MPN Cy-12085G-3016-P4; LCSC Part C968749
C501, C504, C505, C506, C507, C508, C509, C513, C517: 100n; C_0603; LCSC C14663
C502, C503, C511, C512: 100u/6.3V; C_1206_3216Metric; LCSC C16133
C510, C514, C515, C516: 1n; C_0603; LCSC C1588
D501: 1N4148WS; D_SOD-323_1.8x1.4x1.15; LCSC C2128
D502, D503, D504: WS2812B; LED_WS2812B_PLCC4_5.0x5.0mm_P3.2mm; LCSC C2843785
J501: Prog; IDC_2x3_1.27mm; LCSC C42372545
J502: LIGHT/BUTTON; JST_XH_B3B-XH-A_1x03_P2.50mm_Vertical; LCSC C5341202
J503: GPS; JST_XH_B4B-XH-A_1x04_P2.50mm_Vertical; LCSC C5341203
J504: LEDSTRIP; JST_XH_B3B-XH-A_1x03_P2.50mm_Vertical; LCSC C5341202
J506: Conn_01x08_Pin; PinHeader_1x08_P2.54mm_Vertical_SMD_Pin1Left; not fitted
Q501, Q502: AO3400A; SOT-23; LCSC C20917
R501, R502, R503: 10K; R_0603; Farnell 2331736
R504, R505, R506, R507, R508: 100; R_0603; LCSC C22775
TP505: EXT LED; Testpoint_0.9x1.5; not fitted
U501: ESP32-WROOM-32E_(visible_peripherals); ESP32-WROOM-32; LCSC C82899
U502: Ai-Thinker-Ra-02; Ai-Thinker-Ra-02-LoRa; LCSC C90039

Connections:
+3.3V_TOP: C502.1, C503.1, C504.1, C505.1, C506.1, C511.1, C512.1, C513.1, C514.2, C515.2, C516.2, C517.1, J501.2, J502.1, J506.2, R501.1, R502.1, U501.2 (VDD), U502.3 (VDD); also elsewhere on the board
+5V_TOP: BUZZER501.1, C507.1, C508.1, C509.1, D501.1 (K), D502.1 (VDD), D503.1 (VDD), D504.1 (VDD), J503.3, J504.1; also elsewhere on the board
/Top-CPU-V4.0/CS_2: J506.8, U501.13 (MTMS/SCK/CLK/GPIO14)
/Top-CPU-V4.0/ON_TOP: U501.8 (GPIO32); also elsewhere on the board
/Top-CPU-V4.0/RADIO_1: J506.3, U501.37 (MOSI/GPIO23), U502.14 (MOSI)
/Top-CPU-V4.0/RADIO_2: J506.4, U501.31 (MISO/GPIO19), U502.13 (MISO)
/Top-CPU-V4.0/RADIO_3: J506.5, U501.30 (SCK/GPIO18), U502.12 (SCK)
/Top-CPU-V4.0/RADIO_4: J506.6, U501.29 (CS/GPIO5), U502.15 (~NSS)
/Top-CPU-V4.0/RADIO_5: J506.7, U501.16 (MTCK/MOSI/D3/GPIO13), U502.4 (~RESET)
/Top-CPU-V4.0/RADIO_6: U501.23 (MTDO/CS/CMD/GPIO15), U502.5 (DIO0)
/Top-CPU-V4.0/RX_GPS: J503.2, U501.27 (RXD/GPIO16)
/Top-CPU-V4.0/RX_TOP: U501.33 (SDA/GPIO21); also elsewhere on the board
/Top-CPU-V4.0/TX_GPS: J503.1, U501.28 (TXD/GPIO17)
/Top-CPU-V4.0/TX_TOP: U501.36 (SCL/GPIO22); also elsewhere on the board
/Top-CPU-V4.0/VSAMP_TOP: U501.7 (GPIO35); also elsewhere on the board
BUTTON_LIGHT_TOP: R504.1, U501.10 (GPIO25)
BUTTON_TOP: C510.2, R503.1, R505.1, U501.5 (GPIO39)
BUZZER_TOP: R507.2, U501.26 (D1/GPIO4)
DR0_TOP: J501.6, R501.2, U501.25 (BOOT/GPIO0)
EN_TOP: C501.1, J501.1, R502.2, U501.3 (CHIP_PU/EN)
GND: C501.2, C502.2, C503.2, C504.2, C505.2, C506.2, C507.2, C508.2, C509.2, C510.1, C511.2, C512.2, C513.2, C514.1, C515.1, C516.1, C517.2, D502.3 (VSS), D503.3 (VSS), D504.3 (VSS), J501.4, J503.4, J504.3, J506.1, Q501.2 (S), Q502.2 (S), R503.2, U501.1 (GND), U501.15 (GND), U501.38 (GND), U501.39 (GND), U502.1 (GND), U502.2 (GND), U502.9 (GND), U502.16 (GND); also elsewhere on the board
LEDS_TOP: R508.1, U501.11 (GPIO26)
unnamed: BUZZER501.2, D501.2 (A), Q502.3 (D)
unnamed: D502.4 (DIN), R508.2, TP505.1 (1_1)
unnamed: D502.2 (DOUT), D503.4 (DIN)
unnamed: D503.2 (DOUT), D504.4 (DIN)
unnamed: D504.2 (DOUT), R506.1
unnamed: J502.2, R505.2
unnamed: J502.3, Q501.3 (D)
unnamed: J504.2, R506.2
unnamed: Q501.1 (G), R504.2
unnamed: Q502.1 (G), R507.1
RX_TOP_PROG: J501.5, U501.34 (RXD/GPIO3)
TX_TOP_PROG: J501.3, U501.35 (TXD/GPIO1)

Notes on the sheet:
Manual reset / program enable

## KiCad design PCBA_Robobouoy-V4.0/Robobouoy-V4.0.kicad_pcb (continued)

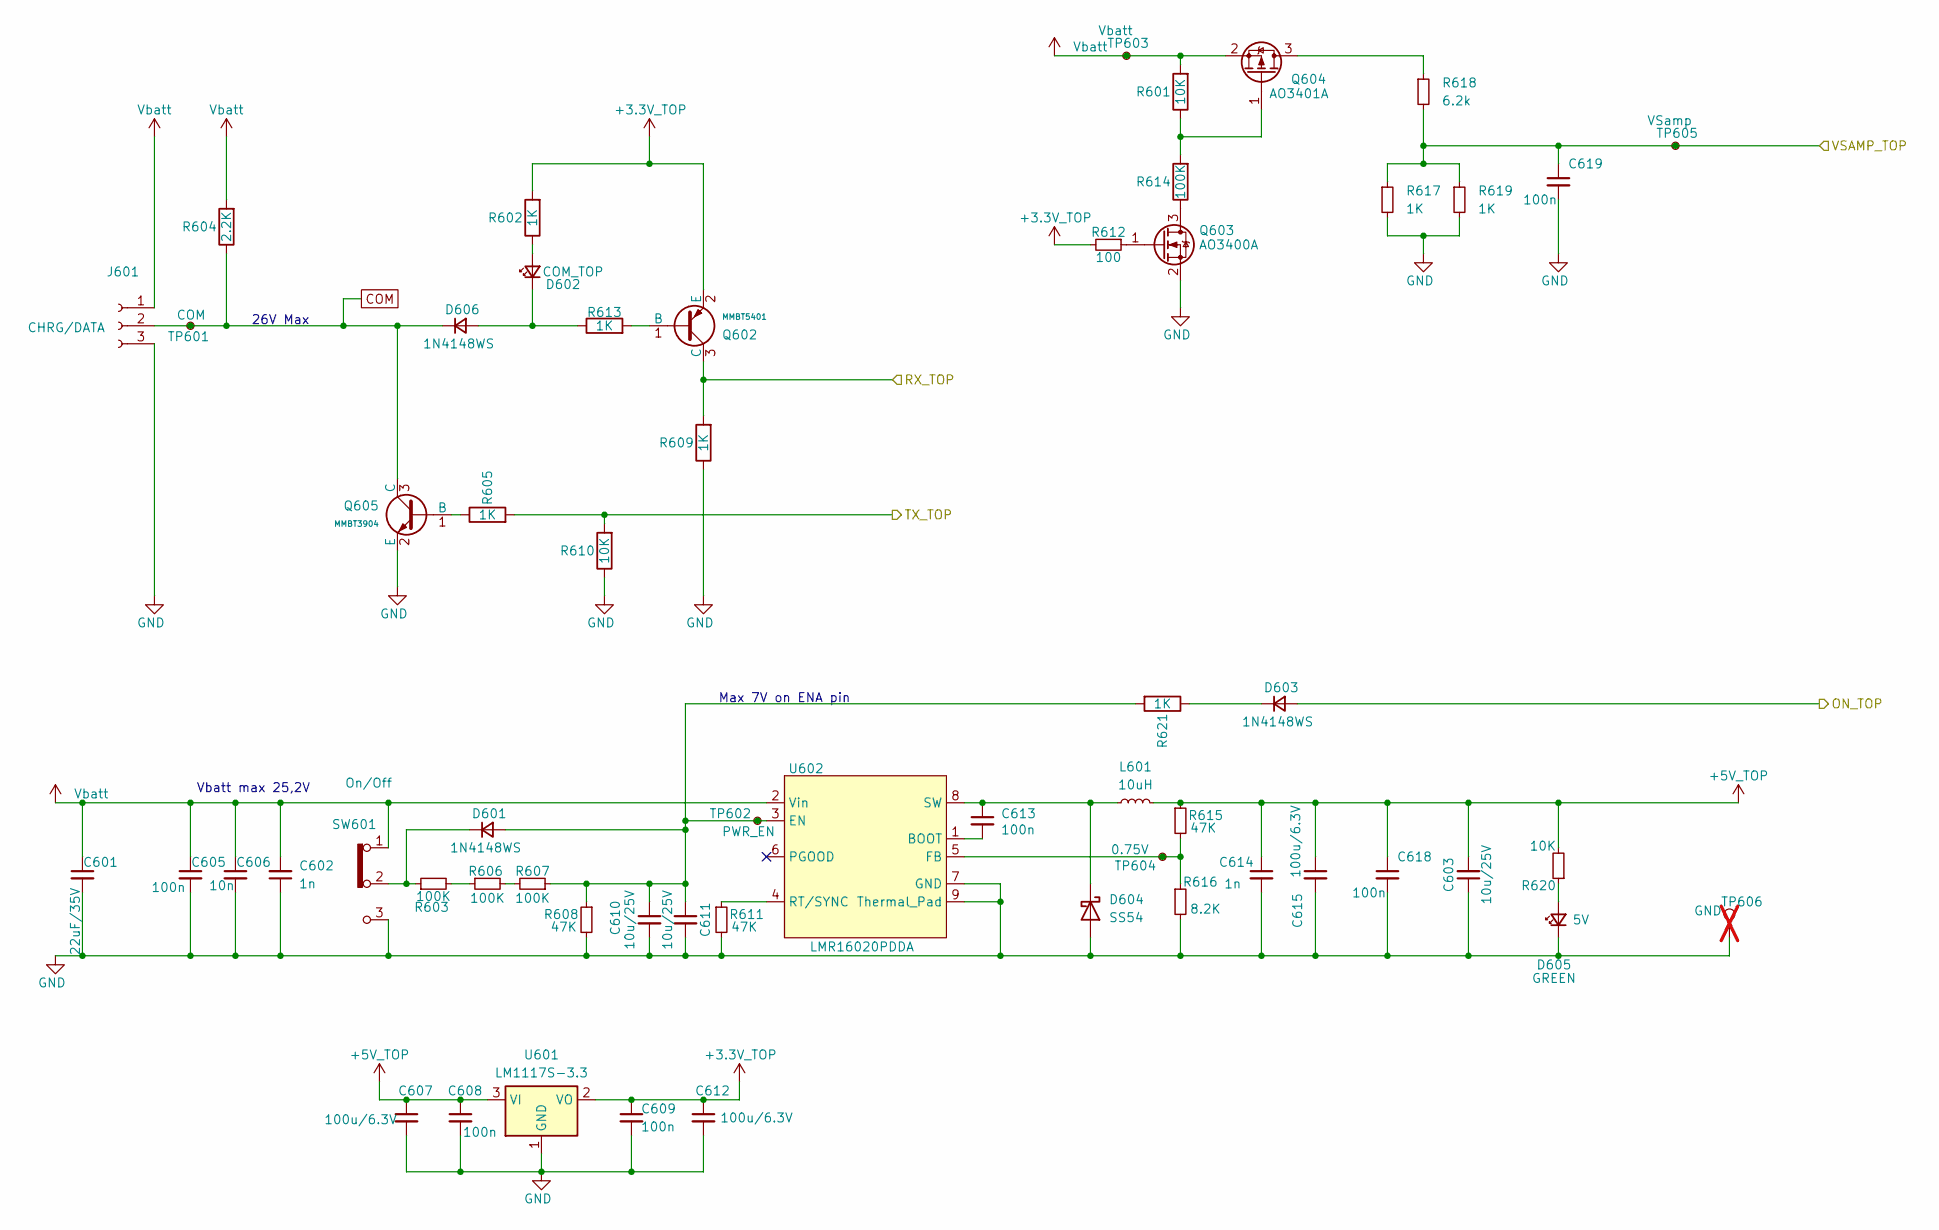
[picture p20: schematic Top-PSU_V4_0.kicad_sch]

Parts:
C601: 22uF/35V; C_1206_3216Metric; LCSC C6119969
C602, C614: 1n; C_0603; LCSC C1588
C603, C610, C611: 10u/25V; C_0805; LCSC C15850
C605, C608, C609, C613, C618, C619: 100n; C_0603; LCSC C14663
C606: 10n; C_0603; LCSC C57112
C607, C612, C615: 100u/6.3V; C_1206_3216Metric; LCSC C16133
D601, D603, D606: 1N4148WS; D_SOD-323_1.8x1.4x1.15; LCSC C2128
D602: COM_TOP; LED_0603; LCSC C2286
D604: SS54; D_SMA; LCSC C22452
D605: GREEN; LED_0603_1608Metric; LCSC C2286
J601: CHRG/DATA; JST_XH_B3B-XH-A_1x03_P2.50mm_Vertical; LCSC C5341202
L601: 10uH; L_6.6x7.0mm; LCSC C2894722
Q602: MMBT5401; Q_SOT-23; Part MMBT5401; LCSC C7420356
Q603: AO3400A; SOT-23; LCSC C20917
Q604: AO3401A; SOT-23; LCSC C15127
Q605: MMBT3904; Q_SOT-23; Part MMBT3904; LCSC C7420353
R601, R610: 10K; R_0603; Farnell 2331736
R602, R605, R609, R613, R617, R619, R621: 1K; R_0603; LCSC C21190
R603, R606, R607: 100K; R_0603; LCSC C25803
R604: 2.2K; R_0603; LCSC C4190
R608, R611, R615: 47K; R_0603; LCSC C25819
R612: 100; R_0603; LCSC C22775
R614: 100K; R_0603; Farnell 2331736
R616: 8.2K; R_0603; LCSC C25981
R618: 6.2k; R_0603; LCSC C4260
R620: 10K; R_0603; LCSC C25804
SW601: On/Off; Header_1x03_P2.54_Male; LCSC C2937625
TP601: COM; Testpad_1
TP602: PWR_EN; Testpad_1
TP603: Vbatt; Testpad_1
TP604: 0.75V; Testpad_1
TP605: VSamp; Testpad_1
TP606: GND; Testpoint_0.9x1.5; not fitted
U601: LM1117S-3.3; SOT223; LCSC C6186
U602: LMR16020PDDA; SOIC-8-1EP_3.9x4.9mm_P1.27mm_EP2.41x3.81mm_ThermalVias; LCSC C190006

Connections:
+3.3V_TOP: C609.1, C612.1, Q602.2 (E), R602.2, R612.2, U601.2 (VO); also elsewhere on the board
+5V_TOP: C603.2, C607.1, C608.1, C614.1, C615.1, C618.1, L601.2, R615.1, R620.2, U601.3 (VI); also elsewhere on the board
/Top-CPU-V4.0/ON_TOP: D603.2 (A); also elsewhere on the board
/Top-CPU-V4.0/RX_TOP: Q602.3 (C), R609.2; also elsewhere on the board
/Top-CPU-V4.0/TX_TOP: R605.2, R610.2; also elsewhere on the board
/Top-CPU-V4.0/VSAMP_TOP: C619.1, R617.1, R618.2, R619.1, TP605.1 (1_1); also elsewhere on the board
COM: D606.1 (K), J601.2, Q605.3 (C), R604.1, TP601.1 (1_1); also elsewhere on the board
GND: C601.2, C602.1, C603.1, C605.2, C606.2, C607.2, C608.2, C609.2, C610.2, C611.2, C612.2, C614.2, C615.2, C618.2, C619.2, D604.2 (A), D605.1 (K), J601.3, Q603.2 (S), Q605.2 (E), R608.2, R609.1, R610.1, R611.2, R616.2, R617.2, R619.2, SW601.3, TP606.1 (1_1), U601.1 (GND), U602.7 (GND), U602.9 (Thermal_Pad); also elsewhere on the board
unnamed: C610.1, C611.1, D601.2 (A), R607.1, R608.1, R621.2, TP602.1 (1_1), U602.3 (EN)
unnamed: D601.1 (K), R603.1, SW601.2
unnamed: D602.2 (A), R602.1
unnamed: D602.1 (K), D606.2 (A), R613.1
unnamed: D603.1 (K), R621.1
unnamed: C613.1, D604.1 (K), L601.1, U602.8 (SW)
unnamed: D605.2 (A), R620.1
unnamed: Q602.1 (B), R613.2
unnamed: Q603.3 (D), R614.1
unnamed: Q603.1 (G), R612.1
unnamed: Q604.3 (D), R618.1
unnamed: Q604.1 (G), R601.1, R614.2
unnamed: Q605.1 (B), R605.1
unnamed: R603.2, R606.1
unnamed: R606.2, R607.2
unnamed: C613.2, U602.1 (BOOT)
unnamed: R615.2, R616.1, TP604.1 (1_1), U602.5 (FB)
unnamed: R611.1, U602.4 (RT/SYNC)
Vbatt: C601.1, C602.2, C605.1, C606.1, J601.1, Q604.2 (S), R601.2, R604.2, SW601.1, TP603.1 (1_1), U602.2 (Vin); also elsewhere on the board

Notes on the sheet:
Vbatt max 25,2V
Max 7V on ENA pin
26V Max

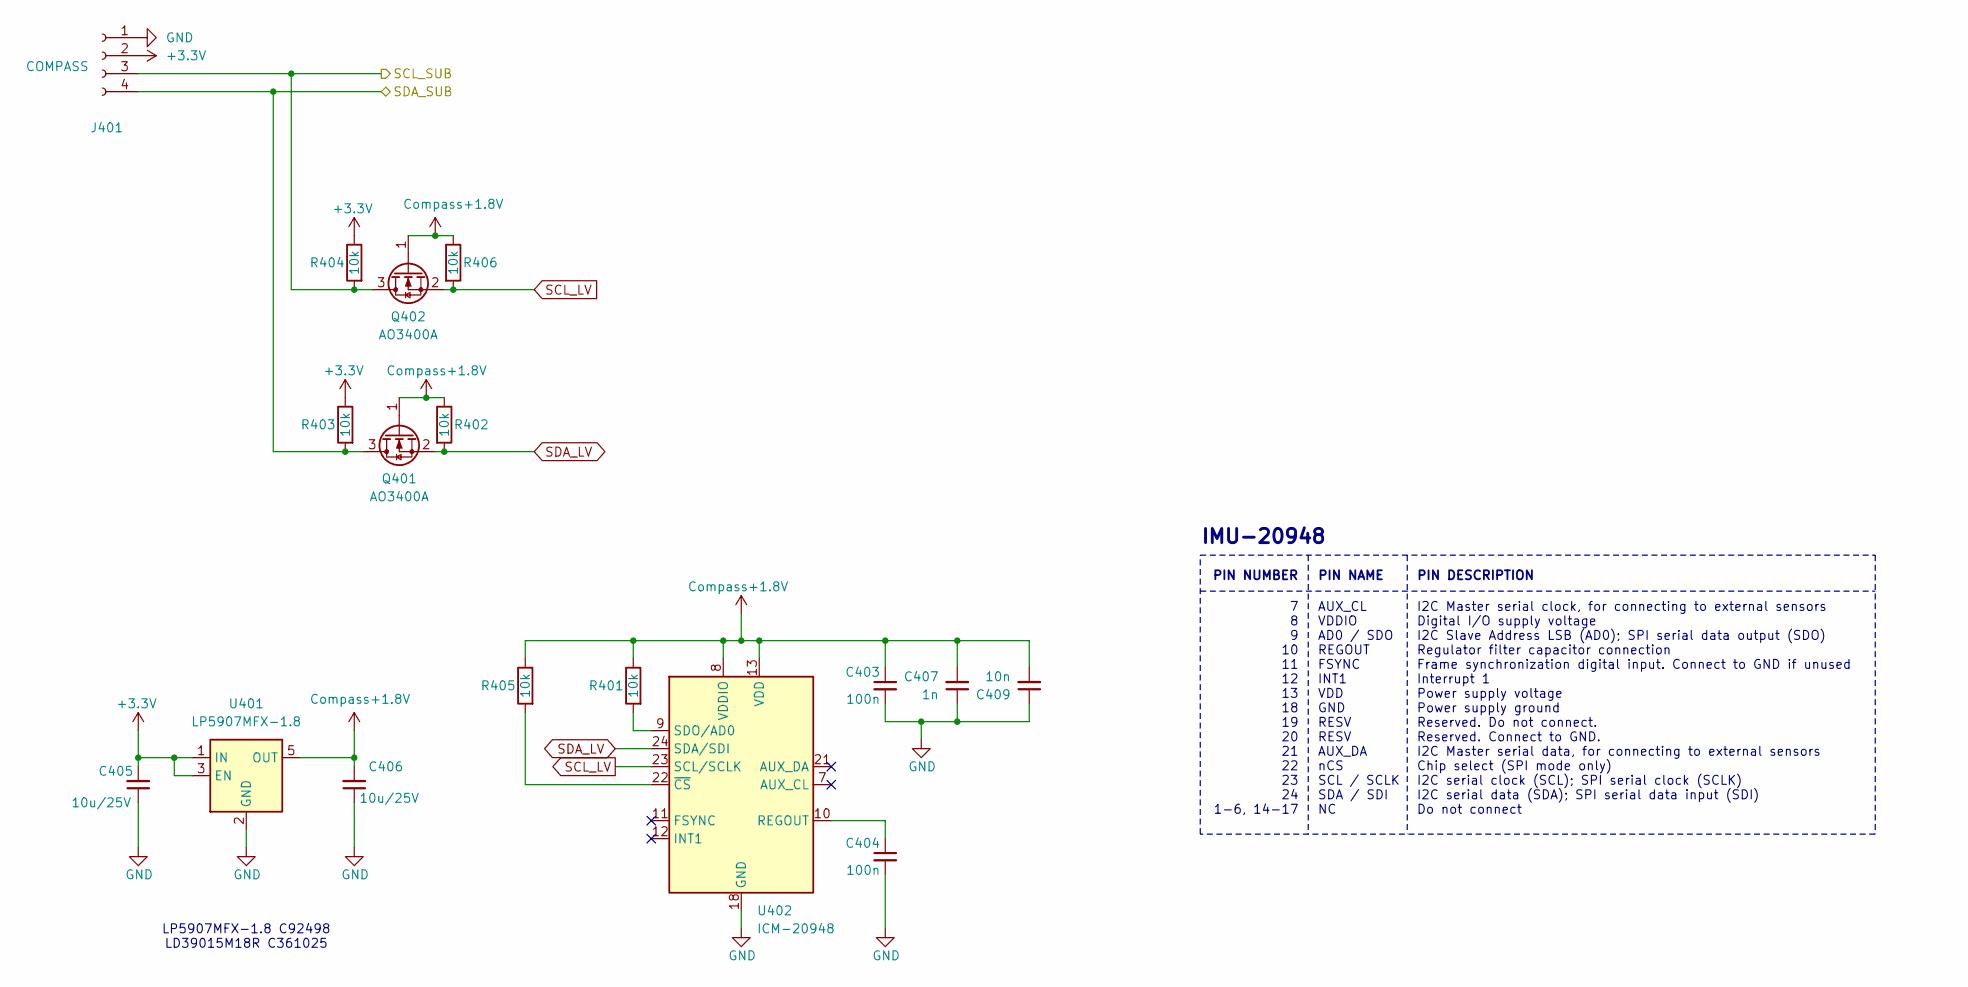
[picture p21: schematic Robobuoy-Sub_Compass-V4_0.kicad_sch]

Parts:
C403, C404: 100n; C_0402; LCSC C1525
C405, C406: 10u/25V; C_0805; LCSC C15850
C407: 1n; C_0402; LCSC C1523
C409: 10n; C_0402; LCSC C15195
J401: COMPASS; JST_XH_B4B-XH-A_1x04_P2.50mm_Vertical; LCSC C5341203
Q401, Q402: AO3400A; SOT-23; LCSC C20917
R401, R402, R403, R404, R405, R406: 10k; R_0402; Farnell 2331736
U401: LP5907MFX-1.8; SOT-23-5
U402: ICM-20948; QFN-24_L3.0-W3.0-P0.40-BL-EP

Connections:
+3.3V: C405.2, J401.2, R403.1, R404.1, U401.1 (IN), U401.3 (EN); also elsewhere on the board
/Suv-CPU-V4.0/SCL_SUB: J401.3, Q402.3 (D), R404.2; also elsewhere on the board
/Suv-CPU-V4.0/SDA_SUB: J401.4, Q401.3 (D), R403.2; also elsewhere on the board
Compass+1.8V: C403.1, C406.2, C407.2, C409.2, Q401.1 (G), Q402.1 (G), R401.1, R402.1, R405.1, R406.1, U401.5 (OUT), U402.8 (VDDIO), U402.13 (VDD)
GND: C403.2, C404.2, C405.1, C406.1, C407.1, C409.1, J401.1, U401.2 (GND), U402.18 (GND), U402.20 (GND); also elsewhere on the board
unnamed: C404.1, U402.10 (REGOUT)
unnamed: R401.2, U402.9 (SDO/AD0)
unnamed: R405.2, U402.22 (~CS)
SCL_LV: Q402.2 (S), R406.2, U402.23 (SCL/SCLK)
SDA_LV: Q401.2 (S), R402.2, U402.24 (SDA/SDI)

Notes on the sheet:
PIN NAME
LP5907MFX-1.8 C92498 LD39015M18R C361025
7 8 9 10 11 12 13 18 19 20 21 22 23 24 1-6, 14-17
IMU-20948
PIN NUMBER
PIN DESCRIPTION
I2C Master serial clock, for connecting to external sensors Digital I/O supply voltage I2C Slave Address LSB (AD0); SPI serial data output (SDO) Regulator filter capacitor connection Frame synchronization digital input. Connect to GND if unused Interrupt 1 Power supply voltage Power supply ground R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
AUX_CL VDDIO AD0 / SDO REGOUT FSYNC INT1 VDD GND RESV RESV AUX_DA nCS SCL / SCLK SDA / SDI NC

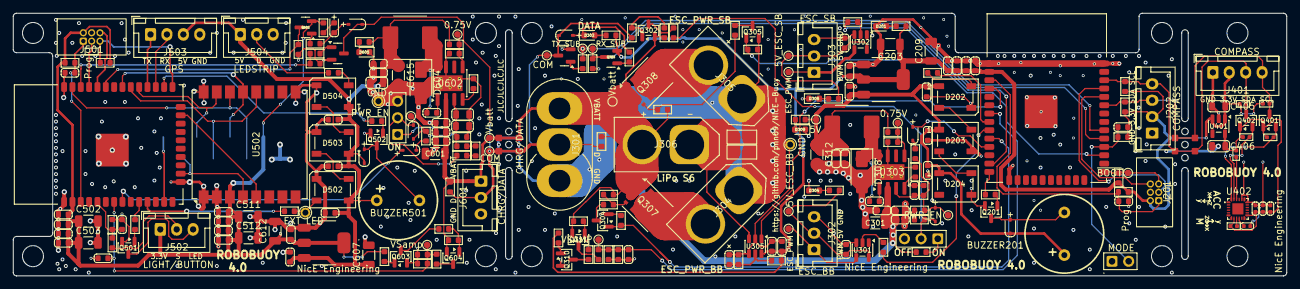
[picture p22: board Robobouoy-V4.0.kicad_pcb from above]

Board: 4 copper layers, 194.0 x 40.0 mm, 258 parts (1 on the bottom side), 122 nets.

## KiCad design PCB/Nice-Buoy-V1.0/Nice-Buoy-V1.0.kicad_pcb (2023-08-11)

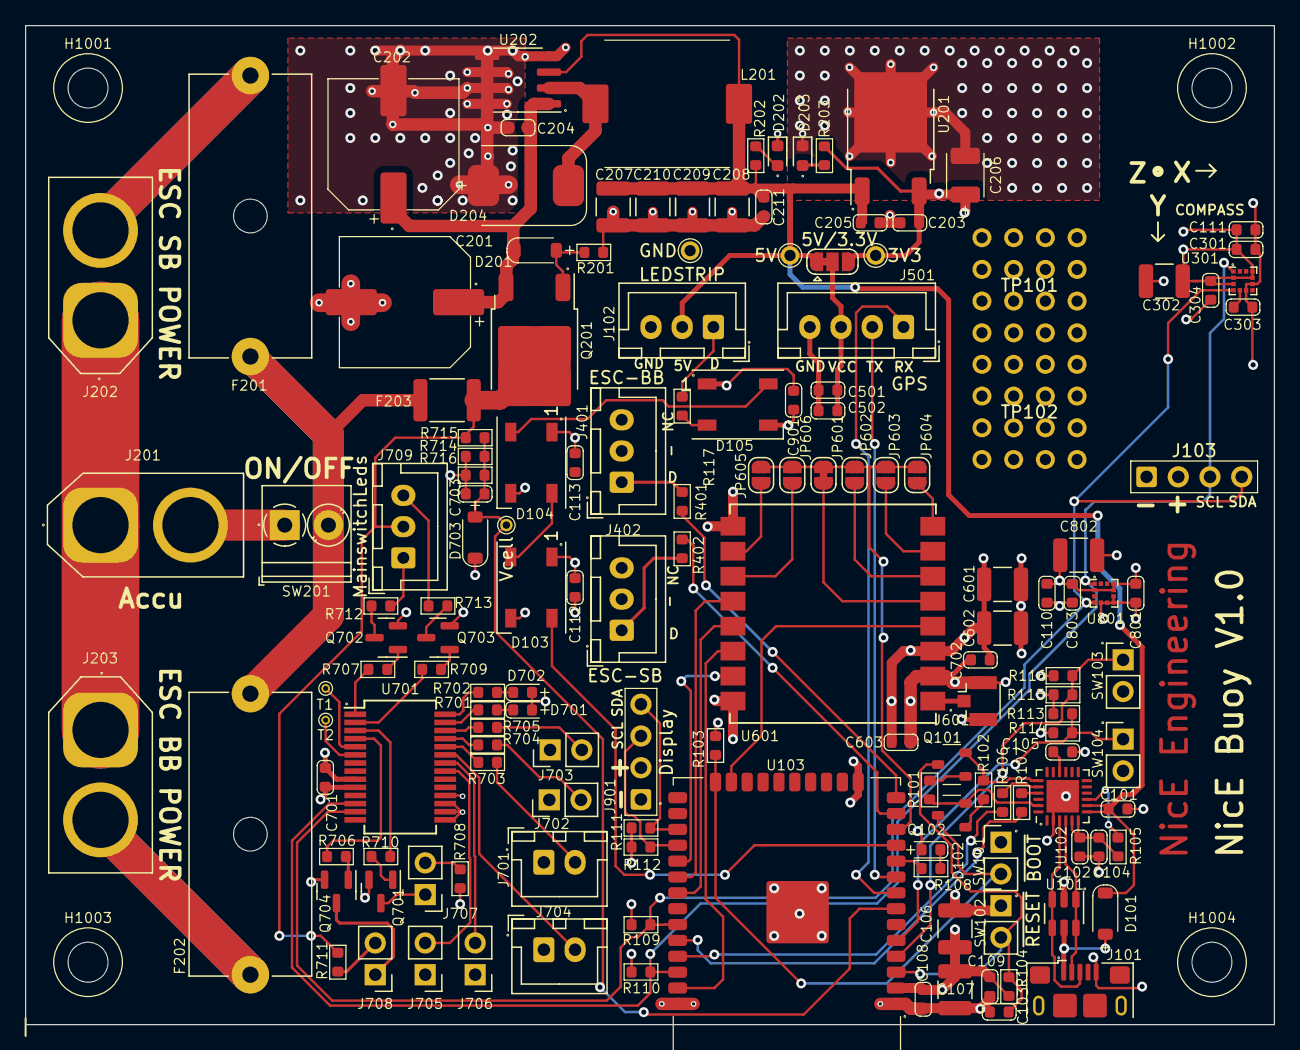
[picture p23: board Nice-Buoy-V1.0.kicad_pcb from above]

Board: 4 copper layers, 100.0 x 80.0 mm, 154 parts (0 on the bottom side), 95 nets.

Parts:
C101, C102, C105: 4.7u; C_0603
C103, C104, C108, C109, C110, C111, C112, C113, C203, C204, C205, C211, C301, C303, C304, C501, C502, C603, C701, C702, C801, C803, C901: 100n; C_0603
C106, C107, C207, C208, C209, C210, C601, C602: 100u/16V; C_1210_3225Metric
C201, C202: 220u/50V; CP_ALU_D10x10.5
C206: 100u/6.3V; CP_TANT_3.5x2.8x1.9
C302, C802: 10u; C_1210_3225Metric
C703: 1n; C_0603
D101, D201, D703: SM4007PL; D_SOD-123_2.85x1.8x1.3
D102, D701: GREEN; LED_0603
D103, D104, D105: WS2812B; LED_WS2812B_PLCC4_5.0x5.0mm_P3.2mm
D202: 5V; LED_0603_1608Metric
D203: 3.3V; LED_0603_1608Metric
D204: SS36-E3/57T; D_SMC_7.1x6.2x2.65
D702: RED; LED_0603
F201, F202: 10A/T; Fuseholder_Cylinder-5x20mm_Schurter_0031_8201_Horizontal_Op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
F203: 3AT; Fuse_1812_4532Metric
H1001, H1002, H1003, H1004: MountingHole; NPTH_M3
J101: USB_B_Mini; USB_Micro-B_Amphenol_10118193-0001LF_Horizontal
J102: LEDSTRIP; JST_XH_B3B-XH-A_1x03_P2.50mm_Vertical
J103, J901: Display; Header_1x04_P2.54_Male
J201: Accu; AMASS_XT60-M_1x02_P7.20mm_Vertical
J202: ESC SB POWER; AMASS_XT60-F_1x02_P7.20mm_Vertical
J203: ESC BB POWER; AMASS_XT60-F_1x02_P7.20mm_Vertical
J401: ESC-BB; JST_XH_B3B-XH-A_1x03_P2.50mm_Vertical
J402: ESC-SB; JST_XH_B3B-XH-A_1x03_P2.50mm_Vertical
J501: GPS; JST_XH_B4B-XH-A_1x04_P2.50mm_Vertical
J601: Conn_Coaxial; U.FL_Hirose_U.FL-R-SMT-1_Vertical
J701: LED1; JST_XH_B2B-XH-A_1x02_P2.50mm_Vertical
J702: LED2; PinHeader_1x02_P2.54mm_Vertical
J703: LED3; PinHeader_1x02_P2.54mm_Vertical
J704: SW1; JST_XH_B2B-XH-A_1x02_P2.50mm_Vertical
J705: SW3; PinHeader_1x02_P2.54mm_Vertical
J706: SW2; PinHeader_1x02_P2.54mm_Vertical
J707: 3.3V switch; PinHeader_1x02_P2.54mm_Vertical
J708: Vbatt switch; PinHeader_1x02_P2.54mm_Vertical
J709: MainswitchLeds; JST_XH_B3B-XH-A_1x03_P2.50mm_Vertical
JP501: 5V/3.3V; SolderJumper-3_P1.3mm_Bridged12_RoundedPad1.0x1.5mm
JP601: D0; SolderJumper-2_P1.3mm_Bridged_RoundedPad1.0x1.5mm
JP602: D1; SolderJumper-2_P1.3mm_Open_RoundedPad1.0x1.5mm
JP603: D2; SolderJumper-2_P1.3mm_Open_RoundedPad1.0x1.5mm
JP604: D3; SolderJumper-2_P1.3mm_Open_RoundedPad1.0x1.5mm
JP605: D4; SolderJumper-2_P1.3mm_Open_RoundedPad1.0x1.5mm
JP606: D5; SolderJumper-2_P1.3mm_Open_RoundedPad1.0x1.5mm
L201: 68uH/3A; L_11.5x10.0mm
Q101, Q102: 2N7002; SOT-23_1.4x3_P0.95
Q201: NCE01P30K; TO-252-2
Q701, Q702, Q703, Q704: MMBT5551L; SOT-23
R101, R102, R103, R104, R105, R113, R114, R115, R116: 10K; R_0603
R106, R107: 120E; R_0603
R108, R203, R701, R702, R706, R707, R709, R710, R714, R716: 1k; R_0603
R109, R110, R111, R112: 2.2k; R_0603
R117, R201, R401, R402, R703, R704, R705, R708, R711: 100; R_0603
R202: 1.5k; R_0603
R712, R713: 4.7k; R_0603
R715: 6.2k; R_0603
SW101: ~{BOOT}; PinHeader_1x02_P2.54mm_Vertical
SW102: ~{RESET}; PinHeader_1x02_P2.54mm_Vertical
SW103: SW_SPST; PinHeader_1x02_P2.54mm_Vertical
SW104: SW2; PinHeader_1x02_P2.54mm_Vertical
SW201: ON/OFF; TerminalBlock_Phoenix_PT-1,5-2-3.5-H_1x02_P3.50mm_Horizontal
TP101: RW1; ReworkPins
TP102: RW2; ReworkPins
TP201: GND; Testpoint_0.9x1.5
TP202: 3V3; Testpoint_0.9x1.5
TP203: 5V; Testpoint_0.9x1.5
TP701: Vcell; Testpoint_0.6x1.0
TP702: T1; Testpoint_0.4x0.7
TP703: T2; Testpoint_0.4x0.7
U101: SRV05-4; SOT-23-6
U102: CP2104-F03-GMR; QFN-24-1EP_4x4mm_P0.5mm_EP2.6x2.6mm
U103: ESP32-WROOM-32E_(visible_peripherals); ESP32-WROOM-32
U201: AP7363; TO-252-2
U202: XL1509-5.0E1; SOIC-8_3.9x4.9mm_P1.27mm
U301: LSM303C; LGA-12_2x2mm_P0.5mm
U601: Ai-Thinker-Ra-01; Ai-Thinker-Ra-01-LoRa
U701: MCP23017_SS; SSOP-28_5.3x10.2mm_P0.65mm
U801: LIS2HH12; LGA-12_2x2mm_P0.5mm

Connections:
+3.3V: C106.1, C107.1, C108.1, C109.1, C110.1, C111.1, C112.1, C113.1, C205.1, C206.1, C301.1, C302.1, C304.1, C601.1, C602.1, C603.1, C701.1, C702.1, C801.1, C802.1, C803.1, C901.1, D102.2 (A), D103.1 (VDD), D104.1 (VDD), D105.1 (VDD), D701.2 (A), D702.2 (A), D703.1 (K), J103.2, J901.2, JP501.3 (B), R103.1, R104.1, R109.1, R110.1, R111.1, R112.1, R113.2, R115.2, R203.2, R708.1, TP202.1, U103.2 (VDD), U201.3 (VO), U301.2 (CS_XL), U301.3 (CS_MAG), U301.9 (VDD), U301.10 (VDDIO), U601.3 (VDD), U701.9 (VDD), U701.18 (~RESET), U801.2 (~CS), U801.9 (Vdd), U801.10 (Vdd_IO)
+5V: C101.2, C203.1, C207.1, C208.1, C209.1, C210.1, C211.1, D101.1 (K), J102.2, JP501.1 (A), L201.2, R202.1, TP203.1, U102.7 (REGIN), U102.8 (VBUS), U201.1 (VI), U202.3 (FB)
+28V: F203.2, J709.2, Q201.2 (D), R711.1, R715.1
/Accumonitor/GREEN: J709.1, R712.1
/Accumonitor/RED: J709.3, R713.2
/Accumonitor/Vbatt: C703.1, D703.2 (A), R714.1, R715.2, R716.1, TP701.1, U103.7 (GPIO35)
/CPU/ESC_BB: R401.1, U103.14 (MTDI/MISO/D2/GPIO12)
/CPU/ESC_SB: R402.1, U103.13 (MTMS/SCK/CLK/GPIO14)
/CPU/GPSRX: J501.1, U103.8 (GPIO32)
/CPU/GPSTX: J501.2, U103.9 (GPIO33)
/CPU/LEDS: D103.4 (DIN), U103.11 (GPIO26)
/CPU/RADIO_1: U103.37 (MOSI/GPIO23), U601.14 (MOSI)
/CPU/RADIO_2: U103.31 (MISO/GPIO19), U601.13 (MISO)
/CPU/RADIO_3: U103.30 (SCK/GPIO18), U601.12 (SCK)
/CPU/RADIO_4: U103.29 (CS/GPIO5), U601.15 (~NSS)
/CPU/RADIO_5: U103.23 (MTDO/CS/CMD/GPIO15), U601.4 (~RESET)
/CPU/RADIO_6: JP601.1 (A), JP602.1 (A), JP603.1 (A), JP604.1 (A), JP605.1 (A), JP606.1 (A), U103.12 (GPIO27)
/CPU/SCL: J103.3, R110.2, U103.36 (SCL/GPIO22), U301.1 (SCL/SPC), U701.12 (SCK), U801.1 (SCL/SPC)
/CPU/SCL_DISP: J901.3, R112.2, U103.28 (TXD/GPIO17)
/CPU/SDA: J103.4, R109.2, U103.33 (SDA/GPIO21), U301.4 (SDA/SDI/SDO), U701.13 (SDA), U801.4 (SDA/SDI)
/CPU/SDA_DISP: J901.4, R111.2, U103.27 (RXD/GPIO16)
/GPS/Vext: C501.1, C502.1, J501.3, JP501.2 (C)
/PSU/ACC: J201.2, SW201.1 (A)
/PSU/POWER: F201.2, F202.2, F203.1, SW201.2 (B)
DR0: Q102.3 (C), R103.2, SW101.2, U103.24 (D0/GPIO2)
DTR: Q102.2 (E), R101.2, U102.23 (DTR)
EN: C103.1, Q101.3 (C), R104.2, SW102.2, U103.3 (CHIP_PU/EN)
GND: C101.1, C102.1, C103.2, C104.1, C105.1, C106.2, C107.2, C108.2, C109.2, C110.2, C111.2, C112.2, C113.2, C201.2, C202.2, C203.2, C204.2, C205.2, C206.2, C207.2, C208.2, C209.2, C210.2, C211.2, C301.2, C302.2, C303.2, C304.2, C501.2, C502.2, C601.2, C602.2, C603.2, C701.2, C702.2, C703.2, C801.2, C802.2, C803.2, C901.2, D103.3 (VSS), D104.3 (VSS), D105.3 (VSS), D202.1 (K), D203.1 (K), D204.2 (A), J101.5 (GND), J102.3, J103.1, J201.1, J202.1, J203.1, J401.2, J402.2, J501.4, J601.2 (Ext), J701.1, J702.1, J703.1, J704.1, J705.1, J706.1, J901.1, Q701.2 (E), Q702.2 (E), Q703.2 (E), Q704.2 (E), R114.1, R116.1, R201.1, R714.2, R716.2, SW101.1, SW102.1, SW103.2 (B), SW104.2 (B), TP201.1, U101.2 (VN), U102.2 (GND), U102.25 (GND), U103.1 (GND), U103.15 (GND), U103.38 (GND), U103.39 (GND), U201.2 (GND), U202.4 (~EN), U202.5 (GND), U202.6 (GND), U202.7 (GND), U202.8 (GND), U301.6 (GND), U301.8 (GND), U601.2 (GND), U601.9 (GND), U601.16 (GND), U701.10 (VSS), U701.15 (A0), U701.16 (A1), U701.17 (A2), U801.5 (RES), U801.6 (GND), U801.7 (GND), U801.8 (GND)
LED1: R703.1, U701.24 (GPA3)
LED2: R704.1, U701.25 (GPA4)
LED3: R705.1, U701.26 (GPA5)
unnamed: D101.2 (A), J101.1 (VBUS), U101.5 (VP)
unnamed: D102.1 (K), R108.2
unnamed: D103.2 (DOUT), D104.4 (DIN)
unnamed: D104.2 (DOUT), D105.4 (DIN)
unnamed: D105.2 (DOUT), R117.2
unnamed: D201.2 (A), Q201.1 (G), R201.2
unnamed: C201.1, C202.1, C204.1, D201.1 (K), Q201.3 (S), U202.1 (VIN)
unnamed: D202.2 (A), R202.2
unnamed: D203.2 (A), R203.1
unnamed: D204.1 (K), L201.1, U202.2 (OUT)
unnamed: D701.1 (K), R701.2
unnamed: D702.1 (K), R702.2
unnamed: J101.3 (D+), U101.3 (IO2), U101.4 (IO3), U102.3 (D+)
unnamed: J101.2 (D-), U101.1 (IO1), U101.6 (IO4), U102.4 (D-)
unnamed: J102.1, R117.1
unnamed: F201.1, J202.2
unnamed: F202.1, J203.2
unnamed: J401.1, R401.2
unnamed: J402.1, R402.2
unnamed: J601.1 (In), U601.1 (ANT)
unnamed: J701.2, R703.2
unnamed: J702.2, R704.2
unnamed: J703.2, R705.2
unnamed: J707.1, Q701.3 (C)
unnamed: J707.2, R708.2
unnamed: J708.1, Q704.3 (C)
unnamed: J708.2, R711.2
unnamed: JP601.2 (B), U601.5 (DIO0)
unnamed: JP602.2 (B), U601.6 (DIO1)
unnamed: JP603.2 (B), U601.7 (DIO2)
unnamed: JP604.2 (B), U601.8 (DIO3)
unnamed: JP605.2 (B), U601.10 (DIO4)
unnamed: JP606.2 (B), U601.11 (DIO5)
unnamed: Q101.1 (B), R101.1
unnamed: Q102.1 (B), R102.1
unnamed: Q701.1 (B), R706.2
unnamed: Q702.1 (B), R707.2
unnamed: Q702.3 (C), R712.2
unnamed: Q703.1 (B), R709.2
unnamed: Q703.3 (C), R713.1
unnamed: Q704.1 (B), R710.2
unnamed: R115.1, R116.2, SW103.1 (A), U103.4 (GPIO36)
unnamed: R113.1, R114.2, SW104.1 (A), U103.5 (GPIO39)
unnamed: R106.2, U102.20 (RXD)
unnamed: R107.2, U102.21 (TXD)
unnamed: C102.2, C104.2, R105.1, U102.5 (VIO), U102.6 (VDD)
unnamed: C105.2, U102.16 (VPP)
unnamed: R105.2, U102.9 (~RSTb)
unnamed: R108.1, U103.10 (GPIO25)
unnamed: C303.1, U301.5 (C1)
unnamed: R701.1, U701.27 (GPA6)
unnamed: R702.1, U701.28 (GPA7)
unnamed: R707.1, U701.1 (GPB0)
unnamed: R709.1, U701.2 (GPB1)
unnamed: R706.1, U701.3 (GPB2)
unnamed: R710.1, U701.4 (GPB3)
unnamed: TP702.1, U701.5 (GPB4)
unnamed: TP703.1, U701.6 (GPB5)
RTS: Q101.2 (E), R102.2, U102.19 (RTS)
RX: R107.1, U103.34 (RXD/GPIO3)
SW1: J704.2, U701.23 (GPA2)
SW2: J706.2, U701.22 (GPA1)
SW3: J705.2, U701.21 (GPA0)
TX: R106.1, U103.35 (TXD/GPIO1)

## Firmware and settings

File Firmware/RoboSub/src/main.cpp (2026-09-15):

#include <Arduino.h>
#include <Wire.h>
#include <RoboTone.h>
#include <RoboCompute.h>
#include "main.h"
#include "freertos/task.h"
#include "io_sub.h"
#include "subwifi.h"
#include "datastorage.h"
#include "leds.h"
#include "esc.h"
#include "compass.h"
#include "buzzer.h"
#include "adc.h"
#include "sercom.h"
#include "pidrudspeed.h"
#include "udplog.h"
// #include "soc/soc.h"
#include "soc/rtc_cntl_reg.h" // needed to disable brownout detector

#define HOST_NAME "RoboBuoySub"
TaskHandle_t compassTaskHandle = NULL; // Task handle for compass task

// SET_AS_NORTH is an ENUMERATOR in RoboCompute.h (msg_t, value 87), not a macro. #ifndef only
// sees macros, so the guard that used to stand here was always true and its #define fired every
// time - rewriting every SET_AS_NORTH below it, including "case SET_AS_NORTH:", to the literal
// 125. The Top and the CYD send 87, so the case could never match and Set as North was dead on
// every path except the Sub's own /set_north web endpoint, which bypasses this dispatcher.
// Do not reintroduce a fallback #define for a name that RoboCompute.h already defines.

#define POWEROFFTIME 60000 * 60 // 60 minutes

// pid subparameter;
RoboStruct mainData;
SemaphoreHandle_t mainDataMutex = NULL;
static RoboStruct udpInMain;
static RoboStruct serDataIn;
static RoboStruct dataIn;
static RoboStruct compassInData;
Message escOut;
static unsigned long buoyId;
static unsigned long PwrOff;
static unsigned long pidTimer = 0;
int subStatus = IDLE;
static LedData mainLedStatus;
static PwrData mainPwrData;
static Buzz mainBuzzerData;
static int wifiConfig = 0;
extern uint32_t global_params_rev;

// timer variables
unsigned long nextSamp = millis();
unsigned long logtimer = millis();
// Button configuration
int buttonState = 0;              // Current state of the button
int lastButtonState = 0;          // Previous state of the button
unsigned long lastPressTime = 0;  // Time of the last press
unsigned long debounceDelay = 50; // Debounce time in milliseconds
int pressCount = 0;               // Count the number of button presses
bool debounce = false;            // Debouncing flag
int presses = 0;

/**
 * @brief Main setup function for the RoboBuoy Sub module.
 * 
 * This function initializes all the necessary hardware pins, enables the power supply,
 * and sets up serial communication. It also initializes memory, WiFi, the compass,
 * inter-task communication queues, and the PID controllers for rudder and speed.
 * Furthermore, it starts various FreeRTOS tasks assigned to specific CPU cores 
 * to handle background operations like WiFi, buzzer, ESCs, LEDs, compass, and serial communication.
 * Finally, it disables the brownout detector to prevent reset on voltage drops.
 * 
 * @param None
 * @return void
 */
void setup()
{
    Serial.begin(115200);
    
    // Drive ESC power pins LOW immediately to keep them completely powered off and silent
    // during the zero-rate gyroscope calibration phase!
    digitalWrite(ESC_SB_PWR_PIN, LOW);
    digitalWrite(ESC_BB_PWR_PIN, LOW);
    pinMode(ESC_SB_PWR_PIN, OUTPUT);
    pinMode(ESC_BB_PWR_PIN, OUTPUT);

    pinMode(PWRENABLE, OUTPUT);
    digitalWrite(PWRENABLE, 1); // enable powersupply
    delay(1000); // Give ICM-20948 and other sensors time to power up completely!
    Wire.begin(21, 22);
    Wire.setClock(400000);
    
    // I2C Scanner
    Serial.println("\n\r--- I2C Scanner ---");
    // mainData.IDr = BUOYIDALL;
    byte error, address;
    int nDevices = 0;
    for(address = 1; address < 127; address++ ) {
        Wire.beginTransmission(address);
        error = Wire.endTransmission();
        if (error == 0) {
            Serial.printf("I2C device found at address 0x%02X\n\r", address);
            nDevices++;
        }
        else if (error==4) {
            Serial.printf("Unknown error at address 0x%02X\n\r", address);
        }    
    }
    if (nDevices == 0) Serial.println("No I2C devices found\n\r");
    else Serial.println("done\n\r");
    Serial.println("-------------------");

    Serial.begin(115200);
    pinMode(BUTTON_PIN, INPUT);
    pinMode(PWRENABLE, OUTPUT);
    digitalWrite(PWRENABLE, 1); // enable batery sample signal
    digitalWrite(PWRENABLE, true);
    mainDataMutex = xSemaphoreCreateMutex();
    printf("Setup running!\n\r");
    printf("Robobuoy Sub Version: %0.1f Sub Build: %s %s\n\r", SUBVERSION, __DATE__, __TIME__);
    mainData.mac = espMac();
    mainData.IDs = mainData.mac;
    mainData.IDr = BUOYIDALL;
    printf("Robobuoy ID: %08x\n\r", mainData.mac);
    initwifi(); // buoyID is mac address esp32
    initMemory();
    pidRudderParameters(&mainData, MEM_GET);
    pidSpeedParameters(&mainData, MEM_GET);
    speedMaxMin(&mainData, MEM_GET);
    CompasOffset(&mainData, MEM_GET);
    computeParameters(&mainData, MEM_GET);
    thrusterInversion(&mainData, MEM_GET);
    thrusterSwap(&mainData, MEM_GET);
    
    initledqueue();
    // Core 0: Start LED Task immediately on boot so we can show dynamic status (e.g. fast yellow blinking) during calibration
    xTaskCreatePinnedToCore(LedTask, "LedTask", 2000, NULL, 2, NULL, 0);

    InitCompass();
    initbuzzerqueue();
    initcompassQueue();
    initserqueue();
    initRudPid(&mainData);
    initSpeedPid(&mainData);
    initescqueue();

    if (digitalRead(BUTTON_PIN) == LOW)
    {
        delay(100);
        if (digitalRead(BUTTON_PIN) == LOW)
        {
            wifiConfig = 1;
        }
    }
    // CORE 0: Network and Telemetry
    xTaskCreatePinnedToCore(WiFiTask, "WiFiTask", 16384, &wifiConfig, configMAX_PRIORITIES - 10, NULL, 0);
    xTaskCreatePinnedToCore(buzzerTask, "buzzTask", 2048, NULL, 1, NULL, 0);
    
    // CORE 1: Real-time Control and Sensors
    xTaskCreatePinnedToCore(EscTask, "EscTask", 2400, NULL, configMAX_PRIORITIES - 5, NULL, 1);
    xTaskCreatePinnedToCore(CompassTask, "CompassTask", 8192, NULL, configMAX_PRIORITIES - 1, &compassTaskHandle, 1);
    xTaskCreatePinnedToCore(SercomTask, "SerialTask", 8192, NULL, configMAX_PRIORITIES - 3, NULL, 1);
    Serial.println("Setup done!");
    // Disable brownout detector
    WRITE_PERI_REG(RTC_CNTL_BROWN_OUT_REG, 0);
}

/**
 * @brief Detects button presses, implementing debounce and long-press detection.
 * 
 * This function reads the state of a physical button and applies a simple debounce mechanism.
 * It counts the number of consecutive presses within a specific time window.
 * If the button is held for an extended period, it registers it as a long press.
 * If a sequence of presses completes without further input, the total count is returned.
 * 
 * @param None
 * @return int The number of presses detected, 0x100 for a long press, or -1 if no complete sequence is detected yet.
 */
int countKeyPressesWithTimeoutAndLongPressDetecton()
{
    // Get the current time
    unsigned long currentTime = millis();
    if (currentTime < debounceDelay)
    {
        return -1; // debounce
    }
    buttonState = digitalRead(BUTTON_PIN);
    // Check if the button is pressed and it's a new press (debounce)
    if (buttonState == LOW && lastButtonState == HIGH && !debounce)
    {
        pressCount++;                     // Increment the button press count
        debounce = true;                  // Set debounce flag
        beep(10, buzzer);                 // short high pitch beep
        debounceDelay = currentTime + 50; // Simple debouncing by adding a delay
        lastPressTime = currentTime;      // Record the time of the last press
    }
    // Reset debounce flag if the button is released
    if (buttonState == HIGH)
    {
        debounce = false;
    }
    // If more than 2 seconds have passed without a press, return the count
    if ((currentTime - lastPressTime) > 500 && pressCount > 0 && buttonState == HIGH)
    {
        if (pressCount == 0x100) // previous detecion was a long press
        {
            pressCount = 0; // Reset the press count after returning
            return -1;      // Return -1 if 0.5 seconds haven't passed yet
        }
        int finalPressCount = pressCount; // Store the current press count
        pressCount = 0;                   // Reset the press count after returning
        return finalPressCount;           // Return the number of key presses
    }
    else if ((currentTime - lastPressTime) > 3000 && pressCount == 1 && buttonState == LOW)
    {

        pressCount = 0x0100;
        return 0X100;
    }
    lastButtonState = buttonState; // Save the last button state
    return -1;                     // Return -1 if 0.5 seconds haven't passed yet
}

/**
 * @brief Processes the detected key presses to trigger specific actions.
 * Examples: 5 presses to calibrate magnetic north, 1 or 10 presses to start compass calibration.
 */
void handleKeyPress(void)
{
    int presses = countKeyPressesWithTimeoutAndLongPressDetecton();
    if (presses > 0)
    {
        Serial.print("Number of key presses: ");
        Serial.println(presses);
        if (presses == 5) // Calibrate compas north
        {
            beep(1, buzzer);
            delay(1000);
            CalibrateCompass();
            presses = -1;
        }
        if (presses == 1) // Calibrate compas
        {
            beep(1, buzzer);
            presses = CALIBRATE_MAGNETIC_COMPASS;
            xQueueSend(compassIn, (void *)&presses, 10); // Start compass calibration
            presses = -1;
        }
        if (presses == 10) // Calibrate compas
        {
            beep(1, buzzer);
            presses = CALIBRATE_MAGNETIC_COMPASS;
            xQueueSend(compassIn, (void *)&presses, 10); // Start compass calibration
            presses = -1;
        }
        if (presses != -1)
        {
            beep(-1, buzzer);
        }
    }
}

static int pendingStatus = -1;

/**
 * @brief Handles changes in the system's operational status.
 * 
 * This function monitors the main status of the RoboBuoy system. Specifically, 
 * it detects if the system transitions into the IDLING state. If so, it ensures 
 * that the ESC (Electronic Speed Controller) speeds are set to 0, stopping the motors, 
 * and then transitions the system to the IDLE state. It also queues the updated 
 * status for serial transmission.
 * 
 * @param stat Pointer to the `RoboStruct` containing the current system state, speed values, and operational status.
 * @return void This function does not return a value.
 */
void handleStatus(RoboStruct *stat)
{
    if (stat->status == IDLING)
    {
        // Wait for motor ramps to reach 0 before fully transitioning
        if (stat->speedBb == 0 && stat->speedSb == 0)
        {
            int nextStatus = (pendingStatus != -1) ? pendingStatus : IDLE;
            stat->speed = 0;
            stat->status = nextStatus;
            initRudPid(stat);
            initSpeedPid(stat);
            xQueueSend(serOut, (void *)stat, 10);
            printf("Ramp down complete. Transitioning to status: %d\r\n", nextStatus);
            pendingStatus = -1;
        }
    }
}

// ---------------------------------------------------------------------------------------------
//  Thruster cleaning - the Sub's half. The sequence itself is in esc.cpp; this is the state
//  around it: what the buoy was doing before, and how it gets back there.
// ---------------------------------------------------------------------------------------------

// The status to go back to when the sequence finishes. "continue in the same status as was before
// entering this function" is the whole requirement, and the only honest way to meet it is to write
// the status down before it is overwritten.
static int cleanRestoreStatus = IDLE;

// Serial of the last CLEAN_THRUSTERS actually acted on, and a floor under how often the sequence
// may run. Both are needed and they cover different things.
//
// The serial rejects a REPEAT: the Top resends the command until it sees CLEANING come back, so
// copies keep arriving after the sequence has started and one that arrived after it FINISHED would
// start the whole thing again. cleanStart() ignores a repeat while it is running, which covers the
// first case but not the second.
//
// The cooldown covers a sender that numbers nothing - a serial console, or a node old enough to
// leave cmdSeq at 0 - where there is no serial to compare. Five seconds, matching the content
// duplicate window the rest of the fleet uses: long enough to outlive an echo, short enough that
// an operator pressing CLEAN NOW again because they want another go is not silently refused.
static uint16_t cleanLastSeq = 0;
static unsigned long cleanCooldownUntil = 0;
#define CLEAN_COOLDOWN_MS 5000

// Tell the Top at once, rather than waiting up to SUBDATA_SERIAL_INTERVAL_MS for the next
// telemetry frame to carry the new status. The Top follows the status, not this frame, so losing
// it costs a quarter of a second of display and nothing else.
static void cleanReport(RoboStruct *ser)
{
    RoboStruct msg = *ser;
    msg.IDs = mainData.mac;
    msg.IDr = BUOYIDALL;
    msg.cmd = CLEANING;
    msg.ack = INF;
    xQueueSend(serOut, (void *)&msg, 0);
}

static void cleanBegin(RoboStruct *ser)
{
    if (ser->status == CLEANING) return;
    if ((long)(millis() - cleanCooldownUntil) < 0)
    {
        printf("CLEAN ignored - cleaned less than %d ms ago\r\n", CLEAN_COOLDOWN_MS);
        udpLog("CLEAN ignored - cooldown, %lu ms left",
               (unsigned long)(cleanCooldownUntil - millis()));
        return;
    }

    cleanStart();
    if (!cleanActive()) return; // refused - a calibration is running, see cleanStart()

    // IDLING is a ramp, not a place. Restoring to it would put the buoy back into a ramp down that
    // has already happened, and pendingStatus behind it would then be applied on top of whatever
    // the cleaning left - so the ramp is resolved here instead and the pending step dropped.
    cleanRestoreStatus = (ser->status == IDLING) ? ((pendingStatus != -1) ? pendingStatus : IDLE)
                                                 : ser->status;
    if (ser->status == IDLING) pendingStatus = -1;

    ser->status = CLEANING;
    ser->tgSpeed = 0;
    // The PIDs are not driving the thrusters for the next ten seconds, and their ramp state and
    // I-term would otherwise come back stale: the I-term would have wound up against an error
    // nothing was acting on, and the ramps would still hold the last full-scale burst.
    resetRudPid();
    resetSpeedPid();
    printf("CLEANING - will return to status %d\r\n", cleanRestoreStatus);
    cleanReport(ser);
}

// Stop cleaning because the operator asked for something else. The command they pressed wins; this
// only makes sure the thrusters and the PIDs are handed over in a known state.
static void cleanInterrupt(RoboStruct *ser)
{
    if (!cleanActive() && ser->status != CLEANING) return;
    cleanAbort();
    cleanCooldownUntil = millis() + CLEAN_COOLDOWN_MS;
    ser->speedBb = 0;
    ser->speedSb = 0;
    escOut.speedbb = 0;
    escOut.speedsb = 0;
    xQueueSend(escspeed, (void *)&escOut, 10);
    resetRudPid();
    resetSpeedPid();
}
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
void loop(void)
{
    {
        char tag[20];
        snprintf(tag, sizeof(tag), "SUB-%08lx", (unsigned long)espMac());
        udpLogBegin(tag);
    }

    mainLedStatus.color = CRGB::Black;
    mainLedStatus.blink = BLINK_OFF;
    mainPwrData.sb = CRGB::Black;
    mainPwrData.bb = CRGB::Black;
    xQueueSend(ledStatus, (void *)&mainLedStatus, 0); // update status led
    xQueueSend(ledPwr, (void *)&mainPwrData, 0);    // update power led
    PwrOff = millis();
    mainData.status = IDLE;
    while (true)
    {
        //***************************************************************************************************
        //      Status change handling
        //***************************************************************************************************
        handleStatus(&mainData);
        //***************************************************************************************************
        //      Timer routines
        //***************************************************************************************************
        handleTimerRoutines(&mainData);
        //***************************************************************************************************
        //      Check front key
        //***************************************************************************************************
        handleKeyPress();
        //***************************************************************************************************
        //      New compass data
        //***************************************************************************************************
        xQueueReceive(compass, (void *)&mainData.dirMag, 0);
        // Imag - the same heading but before the eight point table and the adaptive trim, which is
        // the value that table is indexed by. Published so a calibration can read it directly
        // instead of having to switch the correction off first. See RoboStruct::imag.
        mainData.imag = GetHeadingIron();
        //***************************************************************************************************
        //      new serial message and udp
        //***************************************************************************************************
        handleSerandRfdata(&mainData);
        //***************************************************************************************************
        //      Serial watchdog
        //***************************************************************************************************
        handleSerialTimeOut(&mainData);
        vTaskDelay(pdMS_TO_TICKS(5));
    }
}

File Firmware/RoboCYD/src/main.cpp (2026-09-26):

#include <Arduino.h>
#include <WiFi.h>
#include "cyd_display.h"
#include "cyd_touch.h"
#include "boot_screen.h"
#include "cyd_wifi.h"
#include "cyd_lora.h"
#include "buoy_data.h"
#include "RGBledDriver.h"
#include "robo_config.h"
#include "robo_mesh.h"

// Pick the buoy whose wind reading should drive a course computation.
//
// COMPUTESTART/COMPUTETRACK are executed by whichever buoy receives them, and that buoy squares
// the start line against ITS OWN wind direction. Sending the command to "the first buoy in the
// list" is therefore not safe: a buoy with a failed compass reports wDir/wStd as 0/0, which is
// indistinguishable from a real due-north calm, and the line silently comes out squared to north.
// Same test the wind overlay already uses to decide it has no data to draw.
// Defined further down, next to the rest of the map geometry and the wind picker.
static double track_distance_m(double lat1, double lon1, double lat2, double lon2);
static int pick_wind_reference_buoy();

// Circular mean of two wind readings. Same rule and same reasoning as meanWindDir() in
// RoboCompute.h - kept as a local copy because this screen works from BuoyData, not RoboStructs.
// Vector mean, not arithmetic: 350 and 10 average to 0, not to 180. A buoy reading 0/0 has no wind
// reading at all rather than a northerly, so it is left out.
static float mean_wind_dir(float dirA, float stdA, float dirB, float stdB, float fallback)
{
    bool okA = (dirA != 0 || stdA != 0);
    bool okB = (dirB != 0 || stdB != 0);
    if (!okA && !okB)
        return fallback;
    if (!okB)
        return dirA;
    if (!okA)
        return dirB;
    float ra = dirA * PI / 180.0f, rb = dirB * PI / 180.0f;
    float x = cos(ra) + cos(rb), y = sin(ra) + sin(rb);
    // Exactly opposite readings have no mean direction, and the perpendicular atan2 would return
    // is not one either. A fault, not a wind.
    if (fabs(x) < 1e-6 && fabs(y) < 1e-6)
        return fallback;
    float m = atan2(y, x) * 180.0f / PI;
    return fmod(m + 360.0f, 360.0f);
}

// The two buoys the start line runs between: the closest pair, measured where they ACTUALLY are.
// Not where they are supposed to be - the line drawn on this screen is the one the crew can see
// from the water, and that is the one the wind has to be squared against. Returns false when
// there are not two buoys with a fix.
static bool find_start_line_pair(int &a, int &b)
{
    a = -1;
    b = -1;
    double best = -1;
    for (int i = 0; i < 3; i++)
    {
        if (buoys[i].id == "" || !buoys[i].present)
            continue;
        if (buoys[i].lat == "N/A" || buoys[i].lat == "" || atof(buoys[i].lat.c_str()) == 0)
            continue;
        for (int j = i + 1; j < 3; j++)
        {
            if (buoys[j].id == "" || !buoys[j].present)
                continue;
            if (buoys[j].lat == "N/A" || buoys[j].lat == "" || atof(buoys[j].lat.c_str()) == 0)
                continue;
            double d = track_distance_m(atof(buoys[i].lat.c_str()), atof(buoys[i].lon.c_str()),
                                        atof(buoys[j].lat.c_str()), atof(buoys[j].lon.c_str()));
            if (best < 0 || d < best)
            {
                best = d;
                a = i;
                b = j;
            }
        }
    }
    return (a >= 0 && b >= 0);
}

// The wind to square the line against: the mean of what the two LINE-END buoys report, which is
// the wind across the line rather than one anemometer's opinion of it. The third buoy is the
// upwind mark and is no part of the line, so its reading is left out. Falls back to the single
// reference buoy when there is no pair yet. Returns false when nothing reports wind at all.
static bool start_line_wind(float &wdir, float &wstd)
{
    int a, b;
    if (find_start_line_pair(a, b))
    {
        int ref = pick_wind_reference_buoy();
        float fb = (ref >= 0) ? buoys[ref].wind_dir : 0;
        bool okA = (buoys[a].wind_dir != 0 || buoys[a].wind_std != 0);
        bool okB = (buoys[b].wind_dir != 0 || buoys[b].wind_std != 0);
        if (okA || okB)
        {
            wdir = mean_wind_dir(buoys[a].wind_dir, buoys[a].wind_std,
                                 buoys[b].wind_dir, buoys[b].wind_std, fb);
            // The spread that goes with an averaged direction is the worse of the two, not their
            // mean: it is a confidence figure, and two readings do not make a shifty wind steady.
            wstd = (okA && okB) ? max(buoys[a].wind_std, buoys[b].wind_std)
                                : (okA ? buoys[a].wind_std : buoys[b].wind_std);
            return true;
        }
    }
    int ref = pick_wind_reference_buoy();
    if (ref < 0)
        return false;
    wdir = buoys[ref].wind_dir;
    wstd = buoys[ref].wind_std;
    return true;
}

static int pick_wind_reference_buoy()
{
    for (int i = 0; i < 3; i++)
    {
        if (buoys[i].id != "" && (buoys[i].wind_dir != 0 || buoys[i].wind_std != 0))
        {
            return i;
        }
    }
    return -1;
}

unsigned long lastUIUpdate = 0;
int lastKnownState = -2;             // Used to trigger a static redraw on state change
bool lastSetupState = false;         // Tracks setup screen state transitions
bool lastMannavState = false;        // Tracks manual navigation screen state transitions
bool lastLoadedState = false;        // Tracks setup data loaded transitions
bool lastManFourierCalState = false; // Tracks manual Fourier calibration screen state transitions

bool in_man_fourier_cal_mode = false;
unsigned long mancal_started_ms = 0;
bool mancal_is_dirty = true;
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

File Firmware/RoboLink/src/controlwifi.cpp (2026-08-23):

#include <WiFi.h>

#include <WebServer.h>
#include <ArduinoOTA.h>
#include <AsyncUDP.h>
#include <SPIFFS.h>
#include <WebSocketsServer.h>
#include <DNSServer.h>
#include <ESPmDNS.h>
#include "main.h"
#include "controlwifi.h"

// Instantiate the global WebServer running on standard HTTP port 80 and WebSockets on port 81
WebServer server(80);
WebSocketsServer webSocket(81);

// Captive Portal DNS Server instance to intercept and redirect network traffic.
// All DNS queries (on standard DNS UDP Port 53) will be resolved to the ESP32's local Access Point IP address.
// This forces operating systems (iOS, Android, Windows) to open the local landing page automatically.
DNSServer dnsServer;
const byte DNS_PORT = 53;

//***************************************************************************************************
//      Network policy: RoboLora is a client, never the field AP
//***************************************************************************************************
// Same priority list as the Tops:
//
//      NicE_WiFi  ->  Robo_WiFi  ->  our own LORA_<id> AP
//
// RoboLora used to raise the field AP itself, under the same name the CYD used. Two devices
// broadcasting one SSID on one subnet is two separate networks wearing the same badge, and the
// fleet would split between them. The CYD is the field AP now; we join it like everything else.
static const char *HOME_SSID   = "NicE_WiFi";
static const char *HOME_PASS   = "!Ni1001100110";
static const char *FIELD_SSID  = "Robo_WiFi";
static const char *FIELD_PASS  = "geenanker";
static const char *OWN_AP_PASS = "geenanker";

static bool apActive = false;    // our own AP is currently up
static char ownApSsid[24] = "";  // LORA_73798c
static char mdnsHost[24] = "";   // lora-73798c  ->  http://lora-73798c.local

// Short, readable identity - espMac() folds the last four MAC bytes into the id the logs use, and
// a phone's WiFi list is far easier to search for LORA_xxxxxxxx than for a twelve-hex MAC.
static void build_identity()
{
    snprintf(ownApSsid, sizeof(ownApSsid), "LORA_%08lx", (unsigned long)espMac());
    // mDNS labels may not contain '_', so the hostname is spelled with a hyphen instead.
    snprintf(mdnsHost, sizeof(mdnsHost), "lora-%08lx", (unsigned long)espMac());
}

// The captive portal only works while we are the access point - we will not hijack DNS on someone
// else's network. mDNS covers the other half: http://lora-xxxxxxxx.local resolves in both modes.
static void start_mdns()
{
    // Do NOT call MDNS.begin() or MDNS.end() here. ArduinoOTA.begin() already brings the mDNS
    // responder up under this same hostname, and standing a second one next to it - or tearing
    // it down while OTA still holds it - is exactly what the CYD file already warned about:
    // "dual-allocation heap responder collisions and panics". We only add our own HTTP record
    // on top of the responder OTA created, once.
    static bool advertised = false;
    if (advertised)
    {
        return;
    }
    if (MDNS.addService("http", "tcp", 80))
    {
        advertised = true;
        Serial.printf("[WiFi] reachable as http://%s.local\r\n", mdnsHost);
    }
}

// Try one network, without scanning for it first. WiFi.scanNetworks() is the blocking form: it
// walks all thirteen channels and parks this task for seconds, and with a softAP up that drags the
// single radio off our own channel long enough for a connected client to give up on us. begin()
// does its own short, targeted probe and fails on timeout when the AP is not there.
static bool try_connect(const char *ssid, const char *pass, uint32_t timeoutMs)
{
    Serial.printf("[WiFi] trying '%s' ... ", ssid);
    WiFi.begin(ssid, pass);

    unsigned long start = millis();
    while (WiFi.status() != WL_CONNECTED)
    {
        if (millis() - start > timeoutMs)
        {
            Serial.println("not there");
            WiFi.disconnect();
            return false;
        }
        delay(100);
    }

    // Associated is not the same as usable: starting mDNS or OTA while the lease is still 0.0.0.0
    // takes the lwIP stack - and the chip - down with it.
    while (WiFi.localIP() == IPAddress(0, 0, 0, 0))
    {
        if (millis() - start > timeoutMs + 6000)
        {
            Serial.println("no DHCP lease");
            WiFi.disconnect();
            return false;
        }
        delay(100);
    }

    WiFi.setSleep(WIFI_PS_NONE);
    Serial.printf("joined, IP %s\r\n", WiFi.localIP().toString().c_str());
    return true;
}

void webSocketEvent(uint8_t num, WStype_t type, uint8_t * payload, size_t length) {
    switch(type) {
        case WStype_DISCONNECTED:
            Serial.printf("[%u] Disconnected!\n", num);
            break;
        case WStype_CONNECTED: {
            Serial.printf("[%u] Connected!\n", num);
            break;
        }
        case WStype_TEXT: {
            // Safe copy of payload since it is not guaranteed to be null-terminated
            String message = "";
            message.reserve(length);
            for (size_t i = 0; i < length; i++) {
                message += (char)payload[i];
            }
            message.trim();

            Serial.print("WebSocket RX: ");
            Serial.println(message);

            RoboStruct wsDataIn = {};
            rfDeCode(message, &wsDataIn);
            Serial.printf("Decoded WebSocket RX -> IDr: %08x, IDs: %08x, ack: %d, cmd: %d, status: %d\n", wsDataIn.IDr, wsDataIn.IDs, wsDataIn.ack, wsDataIn.cmd, wsDataIn.status);

            if (wsDataIn.IDs != -1 && wsDataIn.IDs != 0) {
                // Queue the decoded structure safely to webDataIn and set the hasWebCommand flag
                // This lets the main loop safely inject the webpage command right before dispatching,
                // making it 100% immune to being overwritten by background telemetry packets!
                extern RoboStruct webDataIn;
                extern bool hasWebCommand;
                webDataIn = wsDataIn;
                hasWebCommand = true;
                
                // Route to udpIn for thread-safe main task signaling
                xQueueSend(udpIn, (void *)&wsDataIn, 10);
            }
            break;
        }
        default:
            break;
    }
}

static int statik = IDLE;
static RoboStruct msgIdOut;
static RoboStruct topWifiIn;
static RoboStruct udpBuffer;
static RoboStruct udpBufferReceived;

static bool ota = false;
static int8_t id = 0;
static char udpDataIn[MAXSTRINGLENG];
static IPAddress ipTop;
AsyncUDP udp;
QueueHandle_t udpOut;
QueueHandle_t udpIn;
QueueHandle_t wsOutQueue;
// static unsigned long tstart, tstop;
static unsigned long lastUpdMsg = 0;
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

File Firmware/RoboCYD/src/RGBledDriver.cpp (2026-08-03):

#include <Arduino.h>

// For RGB LED
#define RED_LED_PIN 4
#define GREEN_LED_PIN 16
#define BLUE_LED_PIN 17

uint8_t getRedValueFromColor(uint32_t c)
{
    return (c >> 16);
}

uint8_t getGreenValueFromColor(uint32_t c)
{
    return (c >> 8);
}

uint8_t getBlueValueFromColor(uint32_t c)
{
    return (c);
}

void setColor(uint8_t R, uint8_t G, uint8_t B)
{
    // Note: LEDs are "active low", meaning HIGH == off, LOW == on
    analogWrite(RED_LED_PIN, 255 - R);
    analogWrite(GREEN_LED_PIN, 255 - G);
    analogWrite(BLUE_LED_PIN, 255 - B);
}

void ChangeRGBColor(uint32_t color)
{
    setColor(getRedValueFromColor(color), getGreenValueFromColor(color), getBlueValueFromColor(color));
}

void initRGBled()
{
    // set all three pins to output mode
    pinMode(RED_LED_PIN, OUTPUT);
    pinMode(GREEN_LED_PIN, OUTPUT);
    pinMode(BLUE_LED_PIN, OUTPUT);
}

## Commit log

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2024-04-22 pid not working have to chang that. Some progress on the python script
    [LiLlora.cpp, main.cpp]
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2024-04-24 Rudder PID changed base is tan(error) now auto rotate added between 0.5 and 1.5M (zerro speed)
    [LiLlora.cpp, main.cpp]
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2024-05-20 Calibration restored after boot. This was the main issue! All good now
    [PSU_sch.kicad_sch]
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2024-10-21 Still a problem in sub decode incomming pdu message. After crc check the data gets corrupted.
    [compass.cpp, main.cpp]
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2025-07-11 Loads of cahnges. Serial working stabile now (one resistor hardware mod) Ack hadled correct now. Less lora messsages
    [PSU_sch.kicad_sch, Robobuoy-Sub-CPU-v2_1.kicad_sch]
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2026-03-23 feat: enhance UDP monitor UI and fix PID reporting
    - udp_monitor.py: Add translated status labels, DIRDIST controls, Map button, and SETUP popup for PID adjustment. Fix GPS parse bug.
    - RobobuoySub: Fix LORAGET response to correctly assign PIDRUDDER/PIDSPEED command flags.
    - RobobuoyTop: Forward PIDRUDDER/PIDSPEED serial responses to UDP.
    [main.cpp]
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2026-03-25 fix(LoraController): standardize library includes and fix ID iteration
    - Changed 'RoboCompute.h' include from local style to central library style in 'LiLlora.cpp'. This ensures the compiler correctly uses the version defined in 'platformio.ini' and found in 'RobobuoyDependency'.
    - Fixed a logic bug in 'getNextValidID' within 'main.cpp' where an unconditional return inside a loop prevented the function from checking any ID beyond the first array element.
    - Verified fixes by performing a successful PlatformIO build for the 'pico32' environment.
    [LiLlora.cpp, main.cpp]
2026-03-26 fix: PID and MAXMINPWR data flow and ACK handling over LoRa
    - Fix IDs overriding in Top and Sub sercom.cpp to preserve original sender ID.
    - Add support for LORAGETACK (3) in RobobuoyTop and RobobuoySub for PID and MAXMINPWR commands to enable reliable LoRa delivery.
    - Update LoraController LiLlora.cpp to accept messages for ROBOBASE (0x99).
    - Update RoboControl.py to send LORAGETACK instead of LORAGET for setup data requests.
    [LiLlora.cpp, RoboControl.py, main.cpp]
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2026-03-26 feat(RoboLog): Skip UDP request if connection is inactive
    - Added logic to check if UDP is active (messages received in the last 5 seconds) before attempting to send setup requests over UDP.
    - If UDP is inactive, the system now skips the initial UDP attempt and immediately begins requesting data via LoRa to save time.
    [RoboControl.py]
2026-03-26 feat(RoboLog): Implement LoRa as backup for all commands
    - Updated send_custom_udp_command and send_udp_command to check UDP health.
    - If UDP for the target buoy has been active in the last 5 seconds, LoRa is skipped.
    - If UDP is inactive, LoRa is used as a fallback channel.
    [RoboControl.py]
2026-03-26 ui(RoboLog): Remove thrusters and GPS dir from param list
    - Removed 'Bow Thruster (BB)', 'Stern Thruster (SB)', and 'GPS Dir (gpsDir)' from the text-based logged parameters list.
    - Refactored update_gui to ensure the graphical side-bars (thrusters) and windrose vectors continue to update correctly independent of the text labels list.
    [RoboControl.py]
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2026-03-26 feat: make pivot rotation speed adjustable
    - Added pivotSpeed to RoboStruct and communication protocol.
    - Added persistent storage for pivotSpeed in Sub firmware.
    - Replaced hardcoded 0.2 multiplier with adjustable pivotSpeed in pidrudspeed.cpp.
    - Added Pivot Speed field to Python Setup UI.
    [RoboCompute.cpp, RoboControl.py, datastorage.cpp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]
2026-03-26 fix(storage): resolve NVS key length limit and memory leaks
    - Removed redundant MAC address from softIron/hardIron keys in Sub to keep under 15-char limit.
    - Fixed type mismatch in Sub memBuoyId (changed from int8_t/getChar to uint64_t/getULong64).
    - Added missing storage.end() to initMemory in Top and Sub to prevent unclosed namespaces.
    [datastorage.cpp]
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2026-03-26 Revert "fix(offset calib): add 10s stabilization for return leg"
    This reverts commit 25e55cf35b819a62c4edb75e8d32668abcbb3d88.
    [main.cpp]
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2026-03-26 Fix popup UI, LoRa collisions, and shared library compilation
    - RoboControl: Added scrollbar to setup popup and increased window size.
    - RoboControl: Staggered PID requests over LoRa to prevent packet collisions.
    - RoboControl: Updated setup requests to use ACK=1 (LORAGET) to stop network ACK storms.
    - RoboControl: Added dynamic visual feedback for the setup data loading popup.
    - RoboCompute.h: Removed duplicate msg_t enum assignments to resolve build failure.
    - RoboTone.cpp: Renamed conflicting melody declarations to fix compilation.
    [RoboControl.py]
2026-03-27 Fix LoRa control switch communication and RoboControl setup bugs
    - **RoboCompute:** Fixed LORASET enum commenting bug that offset all subsequent commands by 1.
    - **LoraController:** Corrected Target MAC override in UDP transmissions (now uses
    [LiLlora.cpp, RoboControl.py, adc.cpp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]
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2026-03-30 fix(web): align web interface behavior with python script
    - Fixed Topwifi.cpp HTTP command handler to properly inject RF-simulated messages into the UDP queue for movement commands (LOCKING, DOCKING, IDELING, DIRDIST) so they trigger the correct coordinate computations and state transitions in main.cpp.
    - Ensured DIRDIST command correctly sends the IDELING status to initiate the sub-level state transition.
    - Added Anti-Echo logic in index.html to prevent the Setup modal from populating with temporary zeros before the actual sub data arrives.
    - Updated main.cpp to properly populate local mainData and buoyPara bases with remote setup data.
    - Reduced web interface polling interval from 2000ms t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
    [main.cpp]
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2026-03-30 fix(firmware): Fix compass offset parsing and storage bugs
    - Patched RoboCompute decoder to robustly handle inconsistent NMEA formats for STORE_COMPASS_OFFSET sent from Python vs. C++.
    - Fixed a critical bug in RobobuoySub where the new compass offset was immediately overwritten by the old value upon being saved.
    [RoboCompute.cpp]
2026-03-30 refactor(firmware): remove hardcoded default dock positions
    - Replaced the hardcoded WSVOP dock coordinates in both Top and Sub data storage with a generic 0.0, 0.0 default.
    - Added comments to indicate that the user must set their own dock position.
    - Removed commented-out hardcoded coordinates from RobobuoyTop/src/main.cpp.
    [datastorage.cpp, main.cpp]
2026-03-31 fix: Resolve control synchronization issues and rename dependencies
    - Fix RoboControl.py compass offset and calibration IDs to match firmware.
    - Fix Top buoy race condition where Sub's delayed IDLE status overwrote LOCKED.
    - Fix Top buoy web UI logic for LOCK/DOCK button transitions.
    - Fix Sub buoy PID reset logic to clear the locked flag on mode change.
    - Sync RoboControl GUI display for LOCK/DOCK with web UI behavior.
    - Rename RobobuoyDependency to RoboDependency across all projects.
    [RoboCompute.cpp, RoboControl.py, compass.cpp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]
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2026-04-04 fix: invert all three magnetometer axes for ICM20948 based on empirical data
    [compass.cpp]
2026-04-04 fix: correctly invert y and z axes instead of swapping x/y for ICM20948
    [compass.cpp]
2026-04-04 fix: top buoy properly updates compass offset in its own running config when requested
    [main.cpp]
2026-04-04 fix: top buoy updates running compass offset instantly and sub responds correctly with active values
    [compass.cpp]
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2026-04-14 fix: restore dual compass sensor support and fix I2C initialization
    - Restored ICM20948 and LSM303 dual-sensor logic in RoboSub
    - Moved I2C initialization to start of setup() and added I2C scanner
    - Fixed uninitialized sensor crash with UDP broadcast safety checks
    - Added real-time UDP debug broadcasting for raw compass data (5Hz)
    - Updated web dashboard to correctly report dual-sensor headings
    - Includes today's prior updates to Python control UI and PCB schematics
    [RoboControl.py, adc.cpp, compass.cpp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]
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2026-04-14 feat: enhance dual compass calibration and web dashboard
    - Add NVS persistence for ICM20948 magnetometer calibration factors
    - Implement simultaneous calibration for both LSM303 and ICM20948 sensors
    - Add visual (purple blinking LED) and auditory (buzzer) feedback during calibration
    - Fix NVS key mismatch when storing compass offsets
    - Enhance web dashboard with real-time magnetometer axis bars and calibration trigger
    - Improve heading calculation logic with sensor-specific calibration application
    [compass.cpp, main.cpp]
2026-04-16 fix: comprehensive hardware and communication recovery for RoboSub
    This commit resolves several critical issues affecting the RoboSub's LEDs, buzzer, and dual-compass (LSM303/ICM20948) synchronization and calibration.
    LED and Feedback System:
    - Fixed the 'burning bright white' issue by reverting the FastLED driver to WS2812B with GRB ordering.
    - Corrected LED mapping: LED 0 (SB), LED 1 (Status), LED 2 (BB).
    - Startup sequence set to RGB; normal idle state set to Black.
    - Added 500ms buzzer delay and happy melody (case 5) upon calibration completion.
    - Integrated real-time power bar updates into main control loop.
    Dual-Compass Synchronization:
    - Implemented 90-degree physical mapping for IC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
    [RoboCompute.cpp, RoboControl.py, compass.cpp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]
2026-04-16 fix: stabilize sub led thruster indicators and downgrade fastled
    - Downgraded FastLED to stable v3.6.0 in platformio.ini to resolve a known
    RMT driver bug in recent ESP32 core/FastLED combinations that caused all
    LEDs to lock HIGH (burning bright white).
    - Removed conflicting LED queue updates from the main control loop. The
    EscTask is now the exclusive controller for thruster LED data, preventing
    race conditions that caused rapid flickering.
    - Modified EscTask to transmit raw user-facing motor speeds rather than
    pre-calculated RGB values.
    - Refactored LedTask to specifically target a 3-LED hardware configuration:
    - LED 0 (Starboard): Green for forward (>5%), Red for reverse (< -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
    [main.cpp]
2026-04-19 feat: implement on-device 3D Ellipsoid Fit for soft iron calibration
    - Integrated a self-contained 9-parameter Least Squares Ellipsoid Fit algorithm (MagCalibrator) to replace legacy hard-iron-only min/max calibration.
    - Added support for 3x3 soft iron transformation matrices for both LSM303 and ICM20948 sensors.
    - Updated CalibrateCompass() to collect 3D magnetic point clouds and solve for both hard iron offsets and soft iron scaling/rotation in the field.
    - Implemented automatic fallback to min/max Hard Iron calibration if the ellipsoid fit fails due to insufficient data geometry.
    - Refactored heading calculation to apply the full matrix transformation: Corrected = SoftIronMatrix * (Raw -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
    [compass.cpp]
2026-04-19 fix: report active calibration status to top unit
    When triggered via the web interface, the Top unit (RoboTop) would not blink its LED because the Sub never updated its public status struct to CALIBRATE_MAGNETIC_COMPASS. This commits ensures that mainData.status explicitly tracks the calibration state and returns to IDLE upon completion, so the Top unit properly reflects the active calibration mode.
    [compass.cpp]
2026-04-19 feat: distinct happy/sad audio feedback for compass calibration on both Sub and Top
    - Updated CalibrateCompass() on the Sub to evaluate the success of the 3D Ellipsoid Fit algorithm.
    - Added a happy beep (tune 5) upon successful fit, and a sad beep (tune 3) on fallback to Min/Max.
    - The Sub now temporarily updates its telemetry status to ERROR on failure, allowing the Top unit to read the outcome.
    - (Manual Update) Modified RoboTop's buttonLight function to play beep(3) if sta->status is ERROR, and beep(5) otherwise when completing calibration.
    [compass.cpp]
2026-04-19 feat: enforce positive-forward thruster convention and hardware inversion
    - Enforce 'positive is forward' convention across Python UI, Sub ESCs, and Top LED indicators.
    - Add persistent revBB and revSB thruster inversion flags to RoboStruct and NVS to allow fixing hardware wiring via software.
    - Add GUI checkboxes in RoboControl.py for configuring thruster inversion via SETUPDATA (CMD 83).
    - Fix RoboSub not acknowledging SETUPDATA saves.
    - Filter out JSON compass telemetry from UDP parsing to eliminate crc error console spam.
    - Reduce compass moving average from 30 to 5 samples for faster UI responsiveness.
    - Add test_comms.py script for end-to-end UDP/Serial testing.
    [RoboCompute.cpp, RoboControl.py, compass.cpp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]
2026-04-19 feat: complete ESC refactor, current sensing, and UI telemetry sync
    Sub Buoy (ESC & Power):
    - Swapped raw ledc for ESP32Servo library to resolve PWM timing/timer conflicts.
    - Forced ESC power pins HIGH in setup() for immediate module activation.
    - Implemented a reliable 3-second neutral arming sequence (1500us) for ESC initialization.
    - Added 60s initial grace period and Detach logic to preserve hardware timers during sleep.
    Sub Buoy (PID & ADC):
    - Enabled live current (Amps) sensing from IMON pin and optimized the IIR filter.
    - Restored Speed (ip) and Rudder (ir) I-term telemetry by uncommenting GetITerm calls.
    - Removed problematic SetTunings anti-windup logic that was causing PID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
    [RoboCompute.cpp, RoboControl.py, main.cpp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]
2026-04-21 Fix compass and control bugs across Sub, Top, and Lora units
    - **RoboSub**:
    - Replaced individual sub-sensor getEvent() polling for the ICM20948 with the unified icm.getEvent() to ensure synchronous, updated magnetometer and accelerometer vectors during calibration and heading checks.
    - Added a sanity check in heading_icm() to detect zero-filled soft-iron matrices (caused by empty NVS data) and reset them to an Identity matrix to prevent tan2(0,0) returning a stuck heading of 0.0.
    - Updated the Web UI to expose raw IMU accelerometer arrays in the telemetry JSON block for easier debugging.
    - Added
    orward_ramp logic to
    udderPid to smoothly ramp down the ESC motors when transitioning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
    [compass.cpp, main.cpp]
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2026-04-21 Revert ICM mapping to exactly what worked horizontally, keeping only the correct Z-invert. Bump NUM_DIRECTIONS to 25 to filter out thruster interference.
    [DataInterface.kicad_sch]
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2026-05-22 Compass logic update, performance optimization, and UI extensions
    - Integrated trusted compass implementation with min/max calibration and circular averaging
    - Increased control loop and sensor frequency to 50Hz for better responsiveness
    - Relaxed low-pass filters and increased ramping speeds for snappier thruster reaction
    - Implemented smooth linear blending between Pivot and Normal navigation modes
    - Added web interface controls for Thruster Inversion, Motor Swapping, and Pivot Speed
    - Implemented persistent storage for motor swap configuration
    [compass.cpp, datastorage.cpp, main.cpp]
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2026-05-24 Implement Least Squares compass calibration and fix memory corruption
    - Upgraded compass calibration to use Least Squares Ellipsoid Fit algorithm
    - Refactored compass queue to use float (4-byte) instead of double (8-byte) to fix memory overflow
    - Improved web interface layout: moved windrose below thruster power indicators
    - Prepared calibration button for interactive feedback
    [compass.cpp]
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2026-05-30 Implement hybrid LSM303AGR + ICM20948 compass with diagnostic mode and stability fixes
    - Switch to hybrid sensor setup: LSM303AGR for Magnetometer (0x1E), ICM-20948 for Accelerometer (0x69)
    - Implement robust I2C initialization (10kHz, long timeout) to handle protocol violations
    - Apply final linearity corrections (X/Z centers, 1.288 scaling) and circular averaging (50 samples)
    - Add multi-axis diagnostic headings (XZ, XY, YZ) to web dashboard
    - Fix mathematical singularity in tilt compensation by using Y-axis as reference
    - Restore manual offset functionality and North alignment logic
    [compass.cpp, main.cpp]
2026-05-30 Hybrid Compass V11.1 - Stabilization with vertical offset correction
    - Apply precise vertical Hard-Iron offset (-43.0) for LSM303AGR Mag
    - Stabilize tilt compensation by aligning Mag and Accel frames
    - Add raw XYZ and stored offset display to mobile dashboard
    - Finalize smoothing and North alignment for current hardware configuration
    [compass.cpp]
2026-05-31 V13.6: Final BNO055 Persistence Fix and Core Balancing.
    1. Implemented Atomic Injection for BNO055: Byte-by-byte register writing during startup (CONFIG_MODE) with verification read-back.
    2. Added Mode-Lock Retry: Robustly ensures BNO055 enters the requested operation mode (CONFIG/NDOF) before I2C transactions.
    3. Optimized Core Distribution: Moved Compass and Serial tasks to Core 1, leaving WiFi/Dashboard on Core 0 to eliminate I2C bus interference.
    4. Restored Main Control Loop: Fixed regression where navigation PIDs and status handling were omitted from the main thread.
    5. Enhanced Dashboard UI: Restored dynamic MAC address in title, Windrose canvas, and added real-time 22-byte BNO profil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
    [compass.cpp, datastorage.cpp, main.cpp]
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2026-06-03 feat: Comprehensive firmware update for RoboSub and RoboTop
    RoboSub Updates:
    - Tuned heading error filter (alpha increased to 0.80) to significantly reduce phase lag and overshoot.
    - Improved PID anti-windup logic for smoother transitions.
    - Increased WiFiTask stack size to 16KB to prevent crashes during heavy telemetry.
    - Implemented parameter revision system (global_params_rev) for efficient UI synchronization.
    - Enhanced WiFi auto-connect and explicit failure handling.
    - Added safety limits to the lock radius (min 1.5m) to prevent overlapping with pivot range.
    - Updated Web UI for better clarity and responsive feedback.
    RoboTop Updates:
    - Added comprehensive zero-coordinate checks before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
    [main.cpp]
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2026-06-03 feat: Refactor Monitor UI with 4-window telemetry and fix Buoy ID parsing
    RoboMonitor Updates:
    - Split single raw data log into 4 dedicated windows: UDP IN (lime), UDP OUT (cyan), LoRa IN (yellow), and LoRa OUT (orange).
    - Increased window width to 1400px and enabled horizontal resizing for better telemetry readability.
    - Corrected Buoy ID parsing logic to use the Sender field (fields[0]) instead of Receiver (fields[1]).
    - Updated log_message routing and added CRC/Send error reporting to specific windows.
    - Added UDP command handling logic to prevent overwriting existing serial data in the main loop.
    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
    [RoboControl.py, main.cpp]
2026-06-03 fix: Robust message bridging, optimized telemetry, and fixed setup data corruption
    Core Updates:
    - Implemented 'Smart Bridging' in RoboTop to seamlessly route messages between LoRa and UDP without redundant echos.
    - Optimized RoboDependency library to skip empty data fields in GET/ACK packets, significantly reducing network overhead.
    - Fixed RoboTop data corruption issue where uninitialized structs were being broadcast during setup requests.
    - Added immediate cache-based responses for SETUPDATA in RoboTop for faster UI feedback.
    Monitor & UI:
    - Completely refactored RoboControl.py to fix syntax errors and indentation.
    - Corrected buoy identification logic to use the Sender field (,IDs proto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
    [RoboCompute.cpp, RoboControl.py, main.cpp]
2026-06-03 fix: Robust parsing and bridging to solve SETUPDATA inconsistency
    Monitor Updates:
    - Enforced strict ACK=6 (LORAINF) check for all primary telemetry and setup data.
    - Added hex-only verification for Buoy IDs to prevent simulator artifacts from corrupting target routing.
    - Improved echo prevention logic.
    - Fixed log corruption in handelRfData (correct hex formatting).
    - Improved bridging logic to explicitly handle broadcast IDs (0 and BUOYIDALL).
    - Ensured bridging only happens across different interfaces (preventing local echos).
    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
    [RoboControl.py, main.cpp]
2026-06-03 feat: Major Version 4.0.0 - Comprehensive Protocol & Dashboard Refactor
    This major release overhauls the communication architecture and diagnostic capabilities of the RoboBuoy system.
    - Dashboard: Implemented Quad-Window telemetry (UDP/LoRa IN/OUT) and 1400px wide UI.
    - Protocol: Shifted to strict LORAINF (ACK=6) validation to ensure data consistency.
    - Bridging: Rewrote RoboTop relay logic to eliminate network echos and bridge interfaces efficiently.
    - Optimization: RoboDependency now truncates empty fields in GET/ACK packets for low bandwidth.
    - Stability: Fixed data corruption during Setup handshakes and corrected buoy identification logic.
    - UI: Setup window now features in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
    [main.cpp]
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2026-06-04 feat: Add real-time PID I-term telemetry and align dashboard UI
    - Updated subwifi.cpp to include Rudder (ir) and Speed (ip) I-terms in /data API.
    - Modified index.html to display live I-terms and aligned parameter labels/inputs.
    - Synchronized subwifi.cpp with renamed compass telemetry (global_hdg).
    - Reduced rudder phase lag by disabling heading error filtering in pidrudspeed.cpp.
    - Increased telemetry update rate in main.cpp to 10Hz.
    [compass.cpp, main.cpp]
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2026-06-04 fix(comm): improve setup data synchronization and robust buoy identification
    - Implement 'Collecting data...' overlay in Top web interface with a 5-second timeout.
    - Disable message truncation optimization in RoboCompute to ensure full parameter transfer.
    - Update RoboSub to respond with LORAINF for SETUPDATA requests to avoid truncation.
    - Refactor Top buoy data routing to prioritize local serial data for the Main slot.
    - Implement ID synchronization between Top and Sub controllers.
    - Improve RoboControl.py with better buoy frame identification and packet handling.
    [RoboCompute.cpp, RoboControl.py, datastorage.cpp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]
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2026-06-04 feat(ui): add thruster inversion and swap settings to setup popup
    - Implemented UI controls for BB/SB inversion and thruster swap in index.html.
    - Added backend support in topwifi.cpp to serve and update these settings via /data and /command endpoints.
    - Synchronized RoboControl.py with the updated data structure.
    [RoboControl.py]
2026-06-05 Implement user-defined station-keeping radius (holdRad) across system
    Core changes:
    - RoboCompute Shared Library:
    * Added 'holdRad' (double) to RoboStruct for persistent station-keeping radius.
    * Updated SETUPDATA protocol (index 12) in RoboCode/RoboDecode.
    * Standardized message enum names (LORAGET -> GET, etc.) for cross-interface use.
    * Integrated missing math helpers (calculateAngle, etc.) into the core library.
    - RoboTop Firmware:
    * Added build date/time print on startup for easier version tracking.
    * Updated Web Server to handle 'holdrad' input and synchronize with Sub.
    * Improved SETUPDATA routing logic between Web, Serial (Sub), and Rf interfaces.
    * Added 'sub_status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
    [RoboCompute.cpp, datastorage.cpp, main.cpp]
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
